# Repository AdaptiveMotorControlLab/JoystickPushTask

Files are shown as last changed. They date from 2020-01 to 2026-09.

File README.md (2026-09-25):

# Forelimb Object-Push Task

> ⚠️ **Work in progress.** This repository adapts the 2-axis joystick rig from
> [Mathis et al., 2017](https://doi.org/10.1016/j.neuron.2017.02.049) into a **1D forelimb object-push task**.
> The working rig VIs have been imported, and the rest-pad-to-reward success path is bench-tested.
> The push object is now a 3D-modeled joystick shaft with interchangeable tip-mounted handles
> (bar or rounded cube) meant to sit below the mouse.
> Animal-specific calibration, training presets and safety/edge-case validation remain in progress.

Forked and adapted from the original [JoystickControlSystem](https://github.com/AdaptiveMotorControlLab/JoystickControlSystem)
(Mathis lab). The original rig trained head-fixed mice to *pull* a 2-axis joystick against a lateral
magnetic perturbation. This fork keeps the same LabVIEW architecture and NI-DAQ backbone but reworks the
task into a goal-directed forward *push*.

## Task overview

Each trial:

```
forepaw on rest pad  →  trial starts  →  reach to object  →  push forward
  →  (optional axial resistance; hardware not yet active)  →  object held in target band
  →  auditory success cue  →  short delay  →  lick spout extends  →  water reward  →  spout retracts
```

Key differences from the original task:

- **1D push** instead of 2D pull — the task-relevant axis remains in the existing coordinate structure;
  the lateral axis is physically limited by the existing **1D-axis constrainer**.
- **Bounded target zone** — reward requires the object to *end and remain* within a target distance band (overshoot fails).
- **Rest-pad initiation** — a trial can only start when the object is home (spring-loaded) **and** the
  forepaw is on the rest pad, giving a clean pre-contact trial-start state.
- **Axial-resistance perturbation** (opposing the push) instead of a lateral kick. The mesoscope
  rig uses the original Mathis solenoid (McMaster `69905K25`). The training-rig copy is Ledex
  `195224-230`, received 02/09/26 but not yet installed. Its coil driver, Hydraulik-Kompetenz
  PVA 1.6 0–10 V, was ordered 25/09/26. `Dev1/ao0` / `MagnetPush_Dev1` is reserved for the command.
- **Delayed, retractable reward** with an immediate auditory success cue, separating push execution from
  licking/reward for cleaner neural alignment.
- **Planned session blocks** (via parameter files): Baseline → Random perturbation → Fixed perturbation → Washout.

## Current status

- Canonical VIs imported from the behavioural rig and pushed on 18 August 2026.
- Bench-validated path: object home + FSR paw gate → trial → success cue → adjustable delay → spout
  extension → water → consumption wait → spout retraction.
- The acquisition helper reads joystick X/Y, lick/frame signals and the new rest-pad channel.
- A fresh GitHub copy now opens and completes the full bench sequence on the rig PC using the
  compatible repository helper VIs.
- Safe startup now commands water/cue LOW, spout retract and magnet 0 V. One canonical Stop cleanly
  ends every parallel loop; idle, reward-delay and spout-extended Stop tests passed.
- `deliverWater_RIG1_cue.vi` provides manual day-1 habituation rewards: one Run gives a fixed
  50 ms auditory cue followed by the front-panel-selected water pulse, with no joystick requirement.
- Remaining validation includes repeated-cycle testing and explicit fail/timeout checks. LabVIEW's
  toolbar Abort remains emergency-only because it bypasses normal cleanup.
- STEP models exist for an 89 mm joystick shaft plus two tip-mounted handles: a 38 mm bar and a
  rounded cube with three offset holes. See [`mechanical/README.md`](mechanical/README.md).
- A printed joystick, handle and 1D-axis constrainer are already fitted on the rig. Further
  CAD prints wait until 21 September 2026. The rest-pad FSR was replaced on 8 September 2026,
  taped, and is working. Remaining build work includes spring return and a steel-ring target,
  installing the ordered PVA driver and force-calibrating the Ledex, mouse-specific calibration and training-stage
  controls/presets.

## Hardware

Existing rig hardware:

- NI-DAQ card, **PCIe-6321** (`Dev1` on the live rig)
- Joystick base/readout (Digi-Key 679-2501-ND)
- 3D-printed **1D-axis constrainer** ([STEP model](mechanical/3d-print/joystick-1d-axis-constrainer/README.md))
- 3D-modeled **joystick shaft** and interchangeable handles
  ([cube](mechanical/3d-print/joystick-handle-cube/README.md),
  [bar](mechanical/3d-print/joystick-handle-bar/README.md))

Mechanical adaptation in progress:

- One printed joystick, handle and 1D-axis constrainer are fitted for bench testing. Further
  CAD prints wait until 21 September 2026; compare the rounded cube's three offset holes when
  freezing the final mouse-relative reach and object weight.
- Add spring return to home and the steel-ring / washer target for the axial solenoid.

New components for the push task:

| Role | Component | DAQ channel |
| --- | --- | --- |
| Rest-pad paw sensor | Interlink **FSR 402** (solder tabs, 30-81794) + 10 kΩ divider | `Dev1/ai2` |
| Retractable lick spout | **Actuonix L12-30-50-12-I** linear actuator (0–5 V position mode, 12 V supply) | `Dev1/ao1` |
| Auditory success cue | **Adafruit 5 V active buzzer** (#1536) | `Dev1/port0/line1` |
| Axial resistance | Ledex **`195224-230`** (received 02/09/26; not installed). Driver ordered 25/09/26: Hydraulik-Kompetenz PVA 1.6 0–10 V | reserved `Dev1/ao0`  |
| Water valve | existing solenoid | `Dev1/port0/line0` |

> The validated live NI-MAX configuration, SCB-68A wiring and bench-test history are documented in
> [`RIG_INVENTORY.md`](RIG_INVENTORY.md).

> The PCIe-6321 has two AO channels. The working design reserves AO0 for axial resistance and uses
> AO1 for the lick-spout actuator; the auditory cue therefore uses a digital line.

## Software

The main VI is `Push Behaviour_MCHALABI.vi`. Its required local dependencies are
`avg joystick and frame trig lick3.vi`, `frame counter.vi` and `PushTask Globals.vi`.

The program retains the original occurrence-driven five-state architecture and trajectory logging while
adding the FSR gate, digital success cue, retractable-spout reward sequence and shared normal-stop
signal for all asynchronous loops. It requires LabVIEW and NI-DAQmx. Saved NI-MAX tasks are
machine-local and must be imported or configured on each rig. The validated task/channel map is
documented in [`RIG_INVENTORY.md`](RIG_INVENTORY.md), with the 20 August 2026 NI-DAQmx backup stored at
[`ni-max/JoystickPushTask_NIMAX_2026-08-20.nce`](ni-max/JoystickPushTask_NIMAX_2026-08-20.nce).

## Experimental settings file

The experimental parameters are loaded from a text file, one line per trial
(**27 tab-separated columns**). Columns 1–21 were mapped on 8 September 2026;
reward delay, cue duration and spout timing/voltages were added as columns
22–27 and runtime-tested on the rig on 9 September:
[`parameters/README.md`](parameters/README.md). Push = Y / `ai1`; lateral = X /
`ai0`. Column 19 is Case 0 `timeout`; column 20 is Case 3 `move time`.

Push training files (stages 2–8, including reward-delay ramping) live in
[`parameters/training/`](parameters/README.md). Habituation and perturbation
experiment blocks are not yet file-only stages.

The old front-panel controls remain temporarily as references/fallbacks, but
the live rig water loop now reads those six settings from each trial row. The
edited VI binary still needs transferring back from the rig PC into this
repository.

## Calibration

Water-valve pulse length was measured on the training rig on 8 September 2026.
Use **130 / 185 / 240 ms** for **4 / 6 / 8 µl**. The 200 ms bench default delivered
6.6 µl. Full table, fit and figures:
[`calibration/water-volume.md`](calibration/water-volume.md).

Joystick map (8 September 2026): **push = Y = `Dev1/ai1`** (white), **lateral = X =
`Dev1/ai0`** (red). Home is **2.50 V** / **2.525 V**. An eyeball 10 mm push was
2.50 → 2.20 V (~0.030 V/mm at this handle, vs the old demo 0.05 V/mm). See
[`calibration/joystick-volts-mm.md`](calibration/joystick-volts-mm.md).
Remeasure with a ruler before writing training files. Test all channels in
NI-MAX before running.

## Citation

Please cite the original work this task is built on:

- [Mathis et al., 2017](https://doi.org/10.1016/j.neuron.2017.02.049) — *Somatosensory Cortex Plays an
  Essential Role in Forelimb Motor Adaptation in Mice.*

We greatly thank Dr. Ed Soucy at the Harvard CBS Center for Neuroengineering for the original LabVIEW code
and expert advice throughout the development of this joystick system.

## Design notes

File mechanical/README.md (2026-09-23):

# Mechanical designs

CAD and fabrication files for the forelimb push-task rig: 3D-printed parts and
related build notes.

## Layout

| Folder | Use for |
| --- | --- |
| [3D-printed parts](3d-print/README.md) | 3D-printable meshes and project files (STL, 3MF, STEP, Fusion, etc.) |

Add new parts in a named subfolder (e.g. `3d-print/fsr-mount/`) so
revisions stay grouped. Prefer descriptive filenames with dimensions or revision when useful.

## Push object

CAD added 05 Sep 2026: an 89 mm joystick shaft plus two interchangeable tip-mounted handles.

- [Joystick shaft](3d-print/joystick/README.md)
- [Bar handle](3d-print/joystick-handle-bar/README.md) — 38 mm bar
- [Rounded-cube handle](3d-print/joystick-handle-cube/README.md) — current push-object candidate.
  Three holes set how close the front face sits to the mouse and rest pad, and they also shift
  weight relative to the joystick beneath the object.

The cube is meant to sit below the mouse in the natural forelimb workspace and present a
push-biased surface that discourages grasping like the original pull handles.

## 3D models

- [Joystick shaft](3d-print/joystick/README.md) — 89 mm STEP source and STL export
- [Joystick bar handle](3d-print/joystick-handle-bar/README.md) — 38 mm STEP source and STL export
- [Joystick rounded-cube handle](3d-print/joystick-handle-cube/README.md) — rounded-box STEP source and STL export
- [Joystick 1D-axis constrainer](3d-print/joystick-1d-axis-constrainer/README.md) — 38 × 38 × 41 mm STEP source and STL export
- [Ledex holder](3d-print/ledex-holder/README.md) — holder for the Ledex `195224-230`, 30 mm axis STEP source and STL export

One printed joystick, handle and 1D-axis constrainer are fitted for bench testing. Further
prints wait until 21 September 2026. Still to integrate: spring return to home, the
steel-ring / washer target, and final volts→mm calibration after the below-mouse geometry
is frozen.

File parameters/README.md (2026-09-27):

# Parameter files

Tab-separated doubles, **27 columns**, one line = one trial. Columns 1–21 were
mapped on the live VI on 8 September 2026. Columns 22–27 (reward delay, cue,
spout) are in the files as of 9 September 2026; the loader still has to grow
from 21 to 27 cases or those values are ignored.

## Column map (confirmed)

| Index | File column | Field | Notes |
| ---: | ---: | --- | --- |
| 0 | 1 | `home X1` | **ROI slot X — follows the white / push line** (09/09/26 hand test). Pair with col 3. Loader name “X” is not NI-MAX `ai0`. |
| 1 | 2 | `home Y1` | **ROI slot Y — follows the red / lateral line.** Pair with col 4. |
| 2 | 3 | `home X2` | No ×2 on the live loader (checked 09/09/26). |
| 3 | 4 | `home Y2` | |
| 4 | 5 | `home TO` | ms. Object-in-home **and** FSR paw. |
| 5 | 6 | `start X1` | Unused while `start TO` = 0. |
| 6 | 7 | `start Y1` | |
| 7 | 8 | `start X2` | |
| 8 | 9 | `start Y2` | |
| 9 | 10 | `start TO` | Keep **0**. |
| 10 | 11 | `end X1` | **Push target** (white / `ai1`). Lower V = farther forward. |
| 11 | 12 | `end Y1` | **Lateral** (red / `ai0`). Keep wide around 2.525 V. |
| 12 | 13 | `end X2` | |
| 13 | 14 | `end Y2` | |
| 14 | 15 | `end TO` | ms dwell inside the end box. |
| 15 | 16 | `mag` | Keep **0** until resistance. |
| 16 | 17 | `magtime` | Dummy 25 on zero-force rows. |
| 17 | 18 | `watertime` | ms. 130 / 185 / 240 → 4 / 6 / 8 µl. |
| 18 | 19 | `timeout` | Case 0 inter-trial wait (ms). |
| 19 | 20 | `move time` | Case 3 movement window (ms). **400 is short.** |
| 20 | 21 | `light` | Keep **0**. |
| 21 | 22 | `reward delay` | ms after cue, before spout extend. Stage 6. |
| 22 | 23 | `cue duration` | ms. Bench 50. |
| 23 | 24 | `spout extend` | V. Bench **3.0**. |
| 24 | 25 | `spout settle` | ms. Bench **2000**. |
| 25 | 26 | `consumption` | ms. Bench **2000**. |
| 26 | 27 | `spout retract` | V. Bench **0**. |

Boxes are two corners `(X1, Y1, X2, Y2)`. Write the smaller voltage first in
each pair. **Do not trust the words X and Y.** 09/09/26: a file with the
forward band in the Y slots paid out only when **red** moved. The forward
band now goes in the **X** slots so a white-line push is the target. Likely
cause: after `joysticklickframe_push` was reordered to `[Y, X, FSR]`, Case 3
still compares index 0 to the X box and index 1 to the Y box.

## Shared settings (all written files)

Scale is the 08/09/26 eyeball **0.030 V/mm**, push rest **2.50 V** (lower V =
forward). Remeasure with a ruler before treating millimetres as final.

| Field | Value | Why |
| --- | --- | --- |
| Home X (push) | 2.46–2.54 | Rest 2.50 ± 0.035 |
| Home / end Y (lateral) | 2.40–2.65 | Wide so red noise does not fail the trial |
| `home TO` | 250 ms | User 09/09/26 |
| `start TO` | 0 | Rest pad + home replace the start-box wait |
| `watertime` | 185 ms | ~6 µl |
| `timeout` (ITI) | 1000 ms | |
| `move time` | 30000 ms | Clock still starts at Case 2, not paw lift |
| `mag` / `magtime` / `light` | 0 / 25 / 0 | No resistance yet |
| `reward delay` | 0 ms stages 2–5; stage 6 ramps 0/250/500/1000; 500 ms expert/shadow | Final default can move to 1000 ms after validation |
| `cue duration` | 50 ms | |
| `spout extend` / `retract` | 3.0 V / 0 V | |
| `spout settle` / `consumption` | 2000 / 2000 ms | |

Advance a stage after the criterion on **two consecutive days**. Change only
one important thing at a time.

## Files that exist

| File | Stage | Push end box (X) | ~mm from rest | `end TO` | Rows | Extra |
| --- | --- | --- | --- | --- | --- | --- |
| [push_bench_wide-zone.txt](push_bench_wide-zone.txt) | Hand test | 2.20–2.35 | 5–10 mm, wide | 50 | 80 | delay 0 |
| [training/02_micro_push.txt](training/02_micro_push.txt) | 2 Discovery | 2.15–2.45 | past ~1.7 mm, no far wall | **0** | 200 | delay 0 |
| [training/02_micro_push_day1_5s_8ul.txt](training/02_micro_push_day1_5s_8ul.txt) | 2 Day-1 pilot | 0.00–2.27 | permissive threshold from recalibrated 2.275–2.425 home | **0** | 250 | 100 ms home hold; 5 s move; 8 µl; fixed 3 V spout |
| [training/03_proximal_zone.txt](training/03_proximal_zone.txt) | 3 Proximal | 2.35–2.45 | 1.7–5.0 mm | 50 | 400 | delay 0 |
| [training/04_zone_translate_1.txt](training/04_zone_translate_1.txt) | 4 Shift 1 | 2.31–2.41 | 3.0–6.3 mm | 50 | 400 | delay 0 |
| [training/04_zone_translate_2.txt](training/04_zone_translate_2.txt) | 4 Shift 2 | 2.26–2.36 | 4.7–8.0 mm | 50 | 400 | delay 0 |
| [training/04_zone_translate_3.txt](training/04_zone_translate_3.txt) | 4 Final broad | 2.24–2.35 | 5.0–8.7 mm | 50 | 400 | delay 0 |
| [training/05_zone_refine.txt](training/05_zone_refine.txt) | 5 Refine | 2.27–2.34 | 5.3–7.7 mm, ~2.3 mm wide | 50 | 400 | delay 0 |
| [training/06_delay_0.txt](training/06_delay_0.txt) | 6 Delay 0 | same as expert | same | 50 | 400 | reward delay **0** |
| [training/06_delay_250.txt](training/06_delay_250.txt) | 6 Delay 250 | same | same | 50 | 400 | delay **250** |
| [training/06_delay_500.txt](training/06_delay_500.txt) | 6 Delay 500 | same | same | 50 | 400 | delay **500** |
| [training/06_delay_1000.txt](training/06_delay_1000.txt) | 6 Delay 1000 | same | same | 50 | 400 | delay **1000** |
| [training/07_expert.txt](training/07_expert.txt) | 7 Expert | same as refine | same | 50 | 500 | delay **500** |
| [training/08_shadow.txt](training/08_shadow.txt) | 8 Shadow | same as expert | same | 50 | 300 | delay **500** |

`08_shadow` is geometrically identical to expert (`mag = 0`). The 50 / 75 / 100 / 75
block labels are not in the file; they are session notes until the magnet exists.

Do not load `Full_shoterPull_Training_Task_RIG1` for the push task.

## Stages that are **not** a parameter file

| Stage | Why | What to do instead |
| --- | --- | --- |
| 1 Habituation (cue → water, no push) | Water loop only wakes on Case 4 | Run `deliverWater_RIG1_cue.vi` once per manual reward. It gives a fixed 50 ms cue, then water for the front-panel `Water on time (ms)` value. |
| Rest only (fallback) | Would reward pad contact without a push | LabVIEW if a mouse never touches the pad. Not a default. |
| 6 Delay / retractable spout | Files exist (`06_delay_*`) | Load 0 → 250 → 500; use 1000 only if desired and tolerated. Do not change the zone in those sessions. |
| 8 Shadow block labels | No column for block ID; magnet still absent | Run `08_shadow` as one 300-trial zero-force session. Split 50/75/100/75 later if needed. |
| 9 Experiment (Baseline / Random / Fixed / Washout) | Random/Fixed need a force-calibrated magnet | Baseline ≈ `07_expert`. Do not write `mag ≠ 0` files yet. |

## Front panel during these files

The live rig loader and water loop were extended and runtime-tested on
09/09/26. The six values now come from the file. Keep the old FP controls
temporarily as visible references/fallbacks until the edited VI is transferred
back to this repository and re-tested from a clean copy. Log the selected
filename with the session.

For `02_micro_push_day1_5s_8ul.txt`, set the front-panel
`Session start spout (V)` control to **3.0 V** before Run. The file also writes
3.0 V for both extend and retract, so the spout remains extended throughout
the session; normal Stop still retracts it. Bench testing on 27/09/26 corrected
the loader/water-loop cluster-order mismatch for `reward delay` and
`spout retract`. The front-panel captions were corrected separately without
changing the working underlying labels.

## LabVIEW: loader extension completed on rig 09/09/26

The following implementation was completed and reported working on the rig PC.
The repository `.vi` binary still needs to be replaced with that tested copy.

1. Stop the VI. Save a backup.
2. On the front panel, expand the cluster inside **`exp para array`** from
   21 to 27 numeric fields. Copy six existing DBL fields inside the cluster
   and rename their labels exactly: `reward delay`, `cue duration`,
   `spout extend`, `spout settle`, `consumption`, `spout retract`. If the
   cluster is a typedef, open and edit the typedef instead. The loader cases
   cannot Bundle By Name into fields that do not exist in this cluster.
3. Parameter-loader For Loop: change the **21** to **27** (loop count and any
   “init array of 21 zeros”).
4. Add cases **21–26** on that Case Structure (`i`), same pattern as `home X1`:
   Scan From String `%f` → bundle into a new named field.
   - 21 `reward delay`
   - 22 `cue duration`
   - 23 `spout extend`
   - 24 `spout settle`
   - 25 `consumption`
   - 26 `spout retract`
5. Water loop (the Flat Sequence that already uses `watertime`):
   - Wait after cue LOW → **`reward delay`** from this trial (not the FP)
   - Cue wait → **`cue duration`**
   - Extend write → **`spout extend`**
   - Settle wait → **`spout settle`**
   - After water LOW → **`consumption`**
   - Retract write → **`spout retract`**
   Copy how `watertime` is already unbundled for the current trial.
6. Save. Load `06_delay_250.txt`. Success should wait **250 ms** after the cue
   before the spout moves. Then try `06_delay_0.txt` — spout should move
   immediately after the cue.

Habituation (cue→water with no push) is still a separate LabVIEW mode. These
columns do not create that.

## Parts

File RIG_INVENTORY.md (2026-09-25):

# Live Rig Inventory

> Work in progress. Recorded from NI Measurement & Automation Explorer (NI-MAX) on the animal-facility rig PC.

## DAQ hardware

- Device name: `Dev1`
- Model: **National Instruments PCIe-6321**
- Serial number: `01C8BE45`
- NI-MAX status during inventory: Present
- Device temperature during inventory: approximately 32.8 °C
- Earlier project notes incorrectly assumed PCIe-6251; use the live PCIe-6321 configuration as authoritative.
- `SimDev1` is an NI simulated DAQ device, not the physical rig card; do not assign live tasks to it.

Calibration information shown by NI-MAX:

- External calibration: 13 September 2017
- Recommended next external calibration: 13 September 2019 (overdue)
- Last self-calibration: 13 August 2022

Do not initiate calibration during wiring/inventory. Flag the overdue external calibration to the lab
and decide separately whether traceable analog accuracy is required before experiments.

NI-MAX device configuration:

- Connector 0 accessory setting: None
- `port0` power-up state: all eight lines tristated (high-impedance)

Configuration backup:

- Full NI-DAQmx 17.0 configuration exported from `My System` on 20/08/26 after the X/Y-order fix
  and successful GitHub-copy bench test.
- Repository file:
  [`ni-max/JoystickPushTask_NIMAX_2026-08-20.nce`](ni-max/JoystickPushTask_NIMAX_2026-08-20.nce)
- This is a disaster-recovery snapshot, not a substitute for reviewing physical channels before
  import. Inline DAQmx channels created directly by LabVIEW may not appear as saved tasks.

Official PCIe-6321 capacity:

- 16 single-ended or 8 differential analog inputs
- 2 analog outputs
- 24 bidirectional digital I/O lines
- 4 general-purpose counters (`ctr0`–`ctr3`)

Other devices visible in NI-MAX:

- PS3Eye Camera → `cam2`
- DMK 37BUX287 camera → `cam3`
- Serial port → `COM1`
- USB3 Vision Device (unused) → `USB-0`

## Existing NI-DAQmx tasks

- `joysticklickframe`
- `joysticklickframe_push`
- `Magnets_Dev1`
- `MagnetPush_Dev1`
- `Water_Dev1`
- `SuccessCue_Dev1`
- `LickSpout_Dev1`
- `rest_pad_test_Dev1`
- `success_cue_test_Dev1`
- `lick_spout_motor_test_Dev1`
- `frame counter_Dev1`
- `MyPulseOutputTask`
- `testing1blox_2labviews`

## Live LabVIEW program audit — 12/08/26

- The edited behavioural-rig hierarchy was imported into the repository as
  `Push Behaviour_MCHALABI.vi`; untouched `Pull_Behaviour_march2020` remains the fallback.
- Screenshots confirm the expected parameter loader, five-case trial state machine, occurrence-driven
water loop, and lower occurrence-driven perturbation/laser loop.
- The working push VI now performs:
  `cue HIGH → cue wait → cue LOW → reward delay → spout extend → settle → water HIGH →
  explicit watertime wait → water LOW → consumption wait → spout retract`.
- The lower occurrence loop contains both `Magnets_Dev1` analog writes and `Dev1/ctr1` laser-pulse
generation. Magnet support was preserved but converted to `MagnetPush_Dev1` on AO0 only; the laser
branch was not removed.
- `avg joystick and frame trig lick3.vi` uses `joysticklickframe` with DAQmx Analog 2D
`NChan NSamp`, averages indexed channels 0–3, builds a four-value array, and enqueues it as
`joystick pos`. This 12/08 audit led to the installed `joysticklickframe_push` task, which adds
`Dev1/ai2` as queue element index 2 while keeping the original global task unchanged.
- The attempted LabVIEW **Duplicate hierarchy to new location** copy was deleted because the expected
VI was not present in the selected folder. The entire containing folder was then copied manually
and marked with the suffix `- PushVersion - working`. This is the push-task working hierarchy; the
original `LabView files` folder remains the untouched operational baseline.
- Git cannot automatically merge independently changed `.vi` binaries.
- Core working-VI bench validation passed 18/08/26: first-trial rest-pad gating, cue, spout
extension, primed water delivery, consumption wait and retraction all worked across three spaced
successful trials. Fail/timeout behavior was reported working but still needs an explicit,
documented re-test. Abort-path output cleanup has not been specifically validated.
- Fresh GitHub-copy validation passed on the rig PC 20/08/26 after correcting the NI-MAX X/Y channel
  order and replacing the repository's unusable `frame counter.vi` with the compatible copy from the
  working hierarchy. The main VI opened with a healthy Run arrow and completed the full bench sequence.
- Manual day-1 habituation VI `deliverWater_RIG1_cue.vi` was built and bench-tested on 23/09/26.
  Each Run performs `Dev1/port0/line1 HIGH → 50 ms → LOW`, then the original
  `Dev1/port0/line0 HIGH → Water on time (ms) → LOW` sequence. The cue task is cleared before the
  water task is created, enforcing cue-before-water order. This VI has no joystick requirement and
  does not move the lick spout. Do not run the push VI, `SuccessCue_Dev1`, or
  `success_cue_test_Dev1` concurrently because they share the buzzer line.
- Safe startup/normal shutdown validated 20/08/26:
  - one-shot startup sequence commands `Water_Dev1=False`, `SuccessCue_Dev1=False`,
    `LickSpoutMotor_Dev1=0 V` and `MagnetPush_Dev1=0 V`;
  - stale runtime task references `Magnets` and `frame counter` were corrected to
    `MagnetPush_Dev1` and `frame counter_Dev1`;
  - invalid UI-control references could not stop the asynchronous acquisition/frame-counter VIs, so
    required helper `PushTask Globals.vi` now distributes one Boolean `stop all` signal;
  - the canonical main Stop now ends all parallel loops and returns the Run arrow to idle without DAQ
    errors. Idle, reward-delay and spout-extended Stop tests passed with water/cue OFF and final spout
    retraction.
- Toolbar **Abort Execution** remains emergency-only: it bypasses remaining LabVIEW sequence frames.
  If used after a hang, first make outputs safe when possible and rerun the initializer afterward.

## Confirmed task configuration

### `joysticklickframe`

- Purpose: reads the existing joystick position.
- `X_POS` → `Dev1/ai0`
- `Y_POS` → `Dev1/ai1`
- Input range: −10 V to +10 V
- Terminal configuration: Differential
- Acquisition: Continuous Samples
- Sample rate: 10 kHz

Do not assign `ai0` or `ai1` to the new FSR rest-pad sensor.

### `joysticklickframe_push` — created 12/08/26

- New independent AI task created for the working push-task hierarchy; original
`joysticklickframe` remains unchanged.
- Corrected channel order confirmed 20/08/26 as `Dev1/ai1`, `Dev1/ai0`, `Dev1/ai2`
  (`Y_POS`, `X_POS`, FSR). The first push-task configuration used `ai0`, `ai1`, `ai2`, which
  swapped X/Y relative to the unchanged LabVIEW array-index convention inherited from the old task.
- Final channel configuration: `ai0` and `ai1` differential ±10 V; `ai2` RSE, 0–5 V.
- Final timing: Continuous Samples, 10 samples/read, 10 kHz.
- Saved NI-MAX test passed 12/08/26: joystick X, joystick Y, and FSR signals were all visible
simultaneously; FSR responded as expected.
- Working-copy `avg joystick and frame trig lick3.vi` was updated and saved to select
`joysticklickframe_push`; original hierarchy remains pointed at `joysticklickframe`.
- Working-copy main VI Case 0 now reads queue element index 2 into a `rest pad voltage` indicator;
`rest pad voltage > rest pad threshold (V)` now drives a `paw on rest pad` Boolean indicator.
Starting threshold is 0.10 V pending animal-mounted calibration.
- A new AND combines the original X/Y home-ROI result with `paw on rest pad` before the existing
`home TO` hold logic. The separate inter-trial timeout gate is unchanged.
- Runtime test passed: index-2 FSR voltage and `paw on rest pad` changed correctly when Case 0 became
active after a completed/rewarded trial. The apparent initial failure was expected Case Structure
behavior—the indicator does not update while another case executes.
- Working-VI state shift-register initializer changed from 1 to 0 so sessions start in Case 0.
Fresh-run validation passed 12/08/26: the first trial remained gated until paw contact.

### `Magnets_Dev1`

- Purpose: controls the existing two-axis magnetic perturbation hardware.
- `VoltageOut` → `Dev1/ao0`
- `VoltageOut_0` → `Dev1/ao1`
- Output range: −10 V to +10 V
- Generation mode: 1 Sample (On Demand)
- Both available PCIe-6321 analog outputs are currently included in this task.
- The NI-MAX screen showed 1.1 V as the configured test value for both channels; the task was not run.

`Magnets_Dev1` is retained only as an original/legacy task. The working push VI no longer references
it. Its replacement is `MagnetPush_Dev1` on AO0 only, leaving AO1 exclusively available to
`LickSpout_Dev1`.

### `Water_Dev1`

- Purpose: controls the existing water-solenoid output.
- `DigitalOut` → `Dev1/port0/line0`
- Output type: Digital Line Output
- Generation mode: 1 Sample (On Demand)
- `Invert Line`: unchecked

Physical active-high behavior is verified: NI-MAX False→True→False and the LabVIEW sequence both
produce valve clicks and water. The line must be primed and bubble-free before short pulses are
reliable. Delivered volume was measured gravimetrically on 8 September 2026
(50 pulses per width; empty cup 2.94 ± 0.02 g):

`µl / pulse = 0.0350 × t(ms) − 0.48` (R² = 0.998).

Use **130 ms ≈ 4 µl**, **185 ms ≈ 6 µl**, **240 ms ≈ 8 µl**. The previous 200 ms
bench pulse was 6.6 µl. Full table and figures:
[`calibration/water-volume.md`](calibration/water-volume.md).

### `frame counter_Dev1`

- Purpose: counts incoming frame/synchronization pulses.
- Counter resource: `Dev1/ctr0`
- Input terminal: `PFI8`
- Active edge: Rising
- Initial count: 0
- Direction: Count Up
- Acquisition: 1 Sample (On Demand)

Each LOW→HIGH transition arriving on `PFI8` increments counter 0. Keep both `ctr0` and `PFI8`
reserved for the existing frame synchronization.

### `MyPulseOutputTask`

- Purpose: not yet traced physically; likely an existing synchronization/trigger pulse output.
- Counter resource: `Dev1/ctr1`
- Output terminal: `PFI13`
- Generation: Continuous Pulses
- Idle state: Low
- Initial delay: 0 s
- HIGH time: 10 ms
- LOW time: 10 ms
- Resulting pulse frequency: 50 Hz

Keep both `ctr1` and `PFI13` reserved until the task's physical destination and LabVIEW use are
identified. The PCIe-6321 has four counters: saved tasks account for `ctr0` and `ctr1`; `ctr2` and
`ctr3` are not represented in the saved-task list. The active success buzzer still only needs a
spare ordinary digital-output line.

### `testing1blox_2labviews`

- Likely purpose: legacy/diagnostic analog-input test; confirm before deleting or ignoring.
- `Voltage_0` → `Dev1/ai0`
- `Voltage_1` → `Dev1/ai1`
- Input range: −10 V to +10 V
- Terminal configuration: Differential
- Acquisition: N Samples
- Samples to read: 100
- Sample rate: 1 kHz

This task duplicates the same physical AI channels used by `joysticklickframe`. Saved tasks may
overlap resources; they conflict only if software attempts to reserve/run them simultaneously.
Its finite 100-sample configuration and name suggest a test task, but check LabVIEW references
before removing it.

## Breakout box

- Model: **NI SCB-68A** shielded connector block, 68 screw terminals
- Box label: `rig1`
- Connects to `Dev1` via the 68-pin cable; NI-MAX itself still lists the accessory as "None"
- Contains a custom breadboard/component area already populated with user-added circuitry
- The lid label shows S1/S2 switch diagrams for the onboard temperature sensor. Because the joystick
uses AI0/AI8 in differential mode, the temp sensor must be in the disabled (factory default)
position; confirm the physical switches before touching AI0.

### Red regulator module (joystick power supply)

Traced 04/08/26. This is an adjustable DC-DC converter mounted in the breadboard area:

- `IN+` ← red wire from **terminal 14 (+5 V)**
- `IN−` ← black wire from **terminal 50 (D GND)**
- `OUT+` → yellow wire into the rig enclosure, entering the joystick base
- `OUT−` → grey wire into the rig enclosure, entering the joystick base

This supplies the joystick's excitation voltage, and its trim pot is almost certainly what sets the
documented ~2.55 V resting output. **Do not remove, repower or re-trim this module** — doing so would
silently recalibrate every position reading. Note that this consumes **terminal 14**, so the second
+5 V terminal (**8**) must be used for the FSR excitation.

### Laser interlock — SAFETY CRITICAL

**Terminal 42 (PFI 3 / P1.3)**, with **terminal 7 (D GND)** as its return, is wired to a unit labelled
`MDL-III-635L-200mW` (`DC30041`). That is a **200 mW, 635 nm laser — Class 3B**, driven from the
black key-switched supply beside the breakout box.

- No saved NI-MAX task references PFI 3, so this line is commanded directly from LabVIEW code.
- Never toggle PFI 3 / P1.3, and never run an unknown digital task, while the laser key is enabled.
- Keep the laser supply keyed off during all bench testing of the new hardware.

### Saved NI-MAX tasks are not the full picture

PFI 3 is physically wired to the laser but appears in **no** saved NI-MAX task. LabVIEW therefore
creates at least some DAQmx channels inline. Treat the saved-task list as incomplete and confirm
channel usage against the VI before claiming any line is free.

### SCB-68A terminal map (X Series / 63xx label, verified against NI documentation)

Analog input (differential pairs `AI x+` with `AI x+8`):

| Signal | Terminal | Signal | Terminal |
| --- | --- | --- | --- |
| AI 0 (AI 0+) | 68 | AI 8 (AI 0−)  | 34 |
| AI 1 (AI 1+) | 33 | AI 9 (AI 1−)  | 66 |
| AI 2 (AI 2+) | 65 | AI 10 (AI 2−) | 31 |
| AI 3 (AI 3+) | 30 | AI 11 (AI 3−) | 63 |
| AI 4 (AI 4+) | 28 | AI 12 (AI 4−) | 61 |
| AI 5 (AI 5+) | 60 | AI 13 (AI 5−) | 26 |
| AI 6 (AI 6+) | 25 | AI 14 (AI 6−) | 58 |
| AI 7 (AI 7+) | 57 | AI 15 (AI 7−) | 23 |

- AI GND: 67, 32, 64, 29, 27, 24, 56, 59
- AI SENSE: 62

Analog output:

- AO 0 → 22, AO GND → 55
- AO 1 → 21, AO GND → 54

Digital port 0:

| Line | Terminal | Line | Terminal |
| ---- | --- | ---- | --- |
| P0.0 | 52 | P0.4 | 19 |
| P0.1 | 17 | P0.5 | 51 |
| P0.2 | 49 | P0.6 | 16 |
| P0.3 | 47 | P0.7 | 48 |

- +5 V: 14 and 8
- D GND: 53, 18, 50, 15, 13, 12, 44, 9, 7, 4, 36, 35
- PFI 8 / P2.0 → 37 (frame counter input); PFI 13 / P2.5 → 40 (pulse output)

### Physically occupied terminals (surveyed 04/08/26)

| Terminal | Signal | Connected to |
| --- | --- | --- |
| 68 | AI 0 (AI 0+) | joystick X position |
| 34 | AI 8 (AI 0−) | joystick X position, differential return |
| 33 | AI 1 (AI 1+) | joystick Y position |
| 66 | AI 9 (AI 1−) | joystick Y position, differential return |
| 67 | AI GND | analog ground |
| 27 | AI GND | analog ground |
| 8 | +5 V | FSR divider excitation |
| 65 | AI 2 | FSR rest-pad signal |
| 64 | AI GND | FSR divider return |
| 21 | AO 1 | Actuonix 0–5 V position command |
| 54 | AO GND | Actuonix command/external-PSU common |
| 52 | P0.0 | water solenoid |
| 18 | D GND | water solenoid return |
| 17 | P0.1 | Adafruit success buzzer positive |
| 15 | D GND | Adafruit success buzzer return |
| 14 | +5 V | red regulator module `IN+` |
| 50 | D GND | red regulator module `IN−` |
| 42 | PFI 3 / P1.3 | 635 nm 200 mW laser control |
| 7 | D GND | laser return |

### Terminals confirmed physically empty

- **22 (AO 0)** — reserved for the axial-resistance magnet (EU/CH Ledex equivalent); currently no wire landed
- 37 (PFI 8) and 40 (PFI 13) — not in the occupied list
- AI10 terminal 31 remains unused because FSR AI2 uses RSE, not differential
- Remaining unused P0 lines: P0.2–P0.7

### Analog-output split and current physical state

AO1 terminal 21 is now physically wired to the Actuonix command input. AO0 terminal 22 remains
physically empty until the received training-rig magnet is installed. The old `Magnets_Dev1` task still
contains both channels but is not used by the working push VI; `MagnetPush_Dev1` owns AO0 and
`LickSpout_Dev1` owns AO1.

Consequences:

- An AO channel **is** available for the Actuonix, so the lick spout is no longer blocked.
- Confirmed 12/08/26: this behavioural training rig had **no perturbation magnet hardware**.
- Perturbation magnet hardware already exists on the mesoscope rig (original Mathis tubular solenoid).
- Ordered 27/08/26 from Contact Evolution SA, Payerne and received 02/09/26:
  **Ledex / Johnson Electric `195224-230`** (tubular STA 75L pull, 12 VDC, 7 W)
  (https://shop.contact-evolution.ch/en/home/26325-195224-230.html).
  The Ledex is the Swiss/EU equivalent of the original McMaster `69905K25`. The Ledex is not yet mounted or wired.
  Install **axially** (opposing the push), not laterally.
  Coil driver ordered 25/09/26: Hydraulik-Kompetenz **PVA 1.6 0–10 V**
  (CHF 260; not the 4–20 mA SKU). It is a current-regulated PWM amplifier. AO0 is the
  0–10 V command, and coil power comes from the reserved 12 V supply, not the DAQ pin.
  The Bürkert Type 8605 (`316532`) ordered earlier remains the ~2 December spare unless
  that order is cancelled. Mesoscope-rig drive copying is not the plan.
  Include a steel ring / ferromagnetic target on the push object (Mathis 2017).
  Force-calibrate on the bench; do not assume the paper 2.2 V / 100 ms pulse transfers.
  Keep `mag = 0` until the unperturbed task is stable.
- `Magnets_Dev1` must no longer reserve AO1. Target split: one-channel on-demand magnet task on AO0
  and one-channel on-demand Actuonix task on AO1.
- NI documentation permits one software-timed/on-demand AO task per physical AO channel. Both current
  outputs use on-demand writes, so magnet AO0 and spout AO1 can coexist; hardware-timed AO would
  require a combined task because the PCIe-6321 has one AO timing engine.
- Live LabVIEW magnet-loop audit 18/08/26 shows two `Analog 1D DBL NChan 1Samp` writes using
  `Magnets_Dev1`: one command write and one later reset write. Both can be converted to a new
  one-channel AO0 task without altering the separate counter/laser logic.
- `MagnetPush_Dev1` created 18/08/26: `Dev1/ao0` only, ±10 V, 1 Sample (On Demand). Saved but not
  physically exercised because no magnet was connected on this rig at that time.
- Working-copy LabVIEW magnet task constant changed to `MagnetPush_Dev1`; its two DAQmx Write nodes
  were converted to `Analog DBL 1Chan 1Samp`. Activation writes scalar `mag`; reset writes scalar
  zero; both retain auto-start=True. Magnet code now addresses AO0 only and cannot command AO1.
  Working VI retained a solid Run arrow after the refactor.
- Live water-loop audit 18/08/26 confirms its existing Flat Sequence performs
  `Water_Dev1 HIGH → wait watertime → Water_Dev1 LOW`; new cue/spout frames should wrap these without
  replacing them.
- Final output tasks created 18/08/26:
  - `SuccessCue_Dev1` → `Dev1/port0/line1`, digital one-sample/on-demand
  - `LickSpout_Dev1` → `Dev1/ao1`, 0–5 V, one-sample/on-demand
  Existing test tasks remain saved but must not run concurrently on the same lines.
- Working water loop now begins with `SuccessCue_Dev1 HIGH → 50 ms wait → SuccessCue_Dev1 LOW`
  before the preserved water sequence. Runtime test passed 18/08/26: one brief cue occurred per
  successful trial and stopped cleanly.
- Spout/reward frames added with initial bench defaults: reward delay 0 ms; extend command 1.0 V;
  settle 3000 ms; consumption 2000 ms; retract command 0 V. Both `LickSpout_Dev1` analog writes use
  scalar `Analog DBL 1Chan 1Samp` with auto-start=True.
- First LabVIEW sequence test 18/08/26: actuator made the expected coarse 1.0 V extension, followed
  by slight continued fine extension coincident with its familiar audible settling sound. The
  L12-I requires a continuously held setpoint and uses a fixed internal digital position controller;
  time repeated trials to confirm all fine motion/noise stops within the 3000 ms settle window.
- Bench controls later set to extend=3.0 V, settle=2000 ms, consumption=2000 ms, retract=0 V,
  reward delay=0 ms and cue=50 ms; settling sound/fine movement accepted provisionally.
- Resolved water-delivery diagnostic (18/08/26): an initially dry 200 ms automated pulse failed
  because the tubing contained air. A diagnostic 1000 ms pulse primed the line; the immediately
  repeated 200 ms pulse then worked. The 1000 ms value was diagnostic only and must not be used for animals.
- Immediate post-prime retest at 200 ms worked. Multiple air bubbles were observed in the tubing;
failed short-pulse delivery was therefore caused by an unprimed/air-filled water path, not DAQ or
LabVIEW. Inspect and prime until bubble-free before each session. Volume vs pulse
length was measured 08/09/26; see
[`calibration/water-volume.md`](calibration/water-volume.md).
- Three spaced complete trials then passed with cue, extension, water and retraction on every trial.
  The explicit 200 ms Wait is nominally the same intended duration as original `watertime=200`, but
  exact pulse equivalence has not been electrically measured; functional calibration should use
  delivered water mass/volume.
- Random/Fixed perturbation blocks have not yet been physically bench-tested on this training rig;
  install the ordered PVA 1.6 driver and validate its hardware mapping, force and sign before enabling them.

### Channel availability implications

- The joystick task runs in **differential** mode, so it physically consumes AI 0, AI 8, AI 1 and
AI 9 (terminals 68, 34, 33, 66). `ai2` and above are the genuinely free analog inputs.
- `P0.0` (terminal 52) is the water valve. `P0.1`–`P0.7` are candidate buzzer lines.
- Port 0 lines can source up to 24 mA; PFI lines only 16 mA. The Adafruit #1536 buzzer draws roughly
24 mA at 5 V, so it must use a **port 0** line, and even then it sits at the specification limit —
add a small transistor/MOSFET driver if the tone is weak or the line is loaded.
- Terminal 14 (+5 V) is taken by the regulator module; use **terminal 8** for FSR excitation.

## Still to inspect

- [x] `Magnets_Dev1`: `Dev1/ao0` + `Dev1/ao1`, −10 V to +10 V, on-demand
- [x] AO1 terminal 21 is occupied by the Actuonix command; AO0 terminal 22 remains empty for the magnet
- [x] Confirmed 12/08/26: no perturbation magnet then on training rig; magnet existed on mesoscope rig only
- [x] Ordered 27/08/26: Ledex `195224-230` from Contact Evolution SA (Payerne), the Swiss/EU equivalent of McMaster `69905K25`
- [x] Ledex `195224-230` received 02/09/26; holder STEP model added 03/09/26
- [x] Ordered 25/09/26: Hydraulik-Kompetenz PVA 1.6 0–10 V (CHF 260) as the Ledex coil driver. Not the 4–20 mA SKU. Bürkert Type 8605 / `316532` stays the ~2 December spare unless cancelled
- [ ] Print/fit holder, install the PVA driver, wire AO0 terminal 22 and force-calibrate the Ledex
- [x] `Water_Dev1`: `Dev1/port0/line0`, digital line output, on-demand, not inverted in NI-MAX
- [x] `frame counter_Dev1`: `Dev1/ctr0`, rising edges from `PFI8`
- [x] `MyPulseOutputTask`: `Dev1/ctr1` output on `PFI13`, continuous 50 Hz pulse train
- [ ] Confirm whether PFI 8 / PFI 13 are only connected when the imaging system is attached
- [x] `testing1blox_2labviews`: duplicate AI test on `Dev1/ai0` + `Dev1/ai1`, 100 samples at 1 kHz
- [ ] Search LabVIEW/project references before classifying `testing1blox_2labviews` as unused
- [x] Device capacity checked against PCIe-6321 specification: 16 SE/8 differential AI, 2 AO, 24 DIO, 4 counters
- [x] Physical connector/breakout-box model: NI SCB-68A, labelled `rig1`
- [x] Recorded which SCB-68A screw terminals physically have wires landed in them
- [x] Red breadboard module identified as the joystick supply regulator
- [x] PFI 3 traced to a Class 3B 635 nm laser
- [ ] Audit the VI for inline DAQmx channels not represented in saved NI-MAX tasks
- [ ] Confirm S1/S2 temperature-sensor switch positions

## New channels and planned magnet installation

| Component | Channel | SCB-68A terminals | Status |
| --- | --- | --- | --- |
| FSR 402 rest pad | `Dev1/ai2` | signal → 65, ground → AI GND (64), excitation → +5 V (**8**, not 14) | replaced 08/09/26 after 04/09 tail rip; fixed on rail with protective tape; working. Threshold/hysteresis still to calibrate |
| Adafruit #1536 buzzer | `Dev1/port0/line1` | `+` → 17 (P0.1), `−` → 15 (D GND) | installed; NI-MAX and 50 ms LabVIEW success-cue tests passed |
| Actuonix lick spout | `Dev1/ao1` | signal → 21, reference → AO GND (54), motor power from separate 12 V PSU with shared ground | installed; `LickSpout_Dev1` and full extend/water/retract sequence passed across three spaced trials |
| Axial magnet Ledex `195224-230` | `Dev1/ao0` | command → 22, AO GND shared with drive electronics; coil power **not** from the DAQ pin | coil received 02/09/26; driver ordered 25/09/26 (Hydraulik-Kompetenz PVA 1.6 0–10 V). Not mounted or wired. Mount axially; steel-ring target on push object |

Leave `ao0` (terminal 22) reserved for the Ledex until its drive is installed.

### Buzzer installation — 06/08/26

- Adafruit #1536 manufacturing wash seal removed; buzzer was not washed.
- Positive/long lead wired to terminal 17 (`P0.1`).
- Negative/short lead wired to terminal 15 (`D GND`).
- Direct-drive test chosen for initial prototype. Official nominal current is 15 mA, but independent
measurements report up to approximately 24 mA at 5 V, equal to the PCIe-6321 P0 per-line limit.
Treat direct drive as provisional; stop on DAQ error, weak/unstable output or excessive voltage drop.
- Saved NI-MAX task: `success_cue_test_Dev1`
  - Physical channel: `Dev1/port0/line1`
  - Digital line output, not inverted
  - Generation: 1 Sample (On Demand)
- Final task: `SuccessCue_Dev1` on the same line, one-sample/on-demand.
- Direct LOW→HIGH→LOW test passed on 06/08/26: HIGH produced a loud, clear high-pitched tone and
LOW silenced it; no NI-MAX error reported.
- Buzzer leads subsequently soldered and insulated, connected permanently to terminals 17/15, and
the LOW→HIGH→LOW NI-MAX test passed again.
- Working VI writes HIGH, waits a configurable 50 ms bench duration, then writes LOW immediately on
success. End-to-end runtime test passed.
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

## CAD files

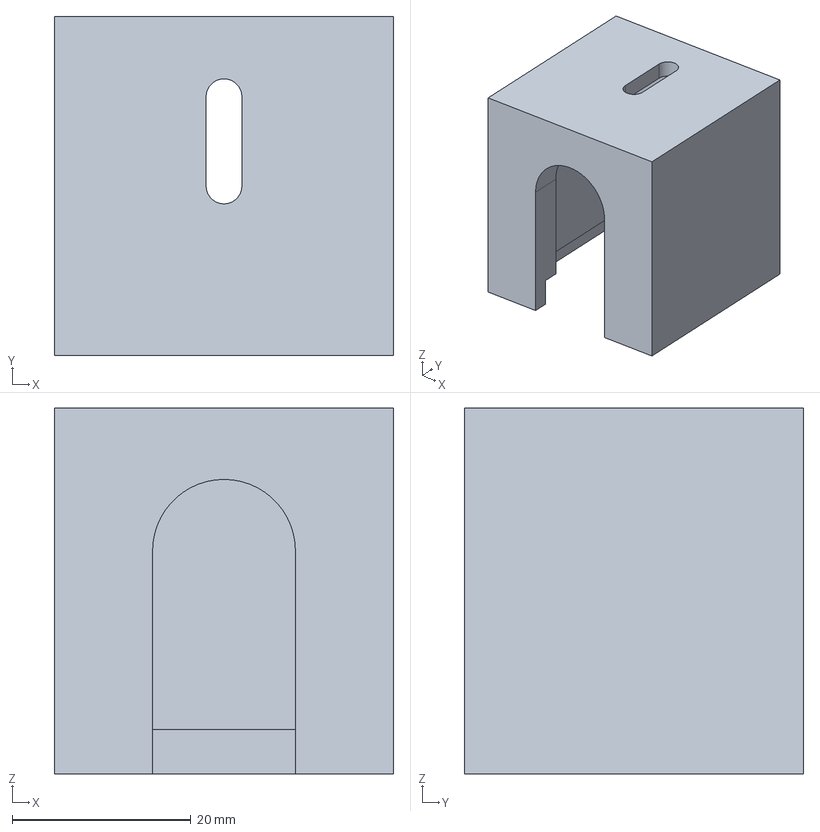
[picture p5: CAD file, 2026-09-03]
mechanical/3d-print/joystick-1d-axis-constrainer/joystick_1d_axis_constrainer_38x38x41.step
38.0 x 38.0 x 41.0 mm

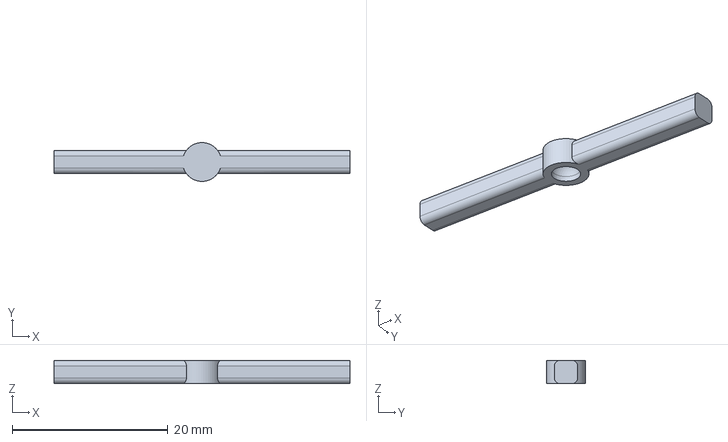
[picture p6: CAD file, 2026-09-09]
mechanical/3d-print/joystick-handle-bar/joystick_handle_bar_38mm.step
38.0 x 4.99 x 3.00 mm

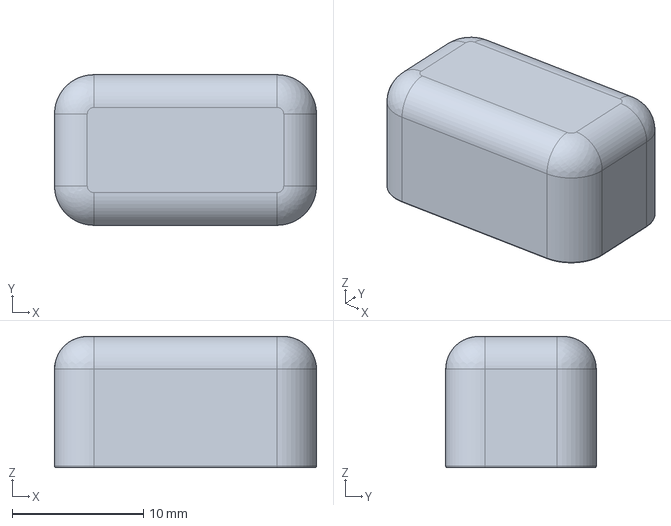
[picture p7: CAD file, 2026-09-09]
mechanical/3d-print/joystick-handle-cube/joystick_handle_cube.step
20.0 x 11.5 x 10.0 mm

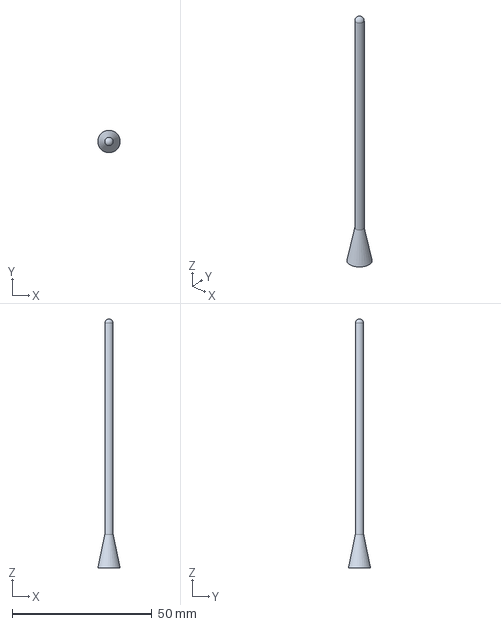
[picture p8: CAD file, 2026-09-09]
mechanical/3d-print/joystick/joystick_89mm.step
7.99 x 8.00 x 89.0 mm

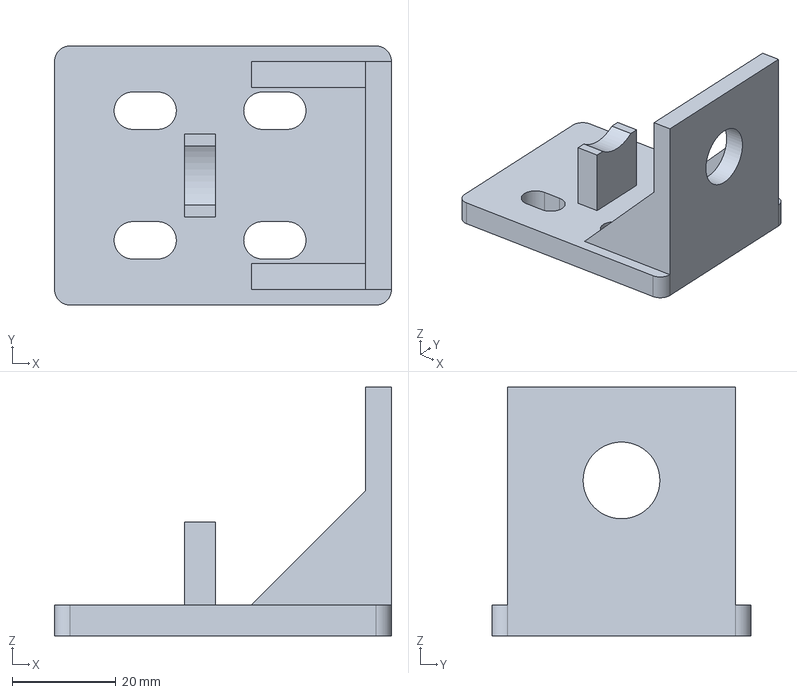
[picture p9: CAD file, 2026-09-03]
mechanical/3d-print/ledex-holder/ledex_195224-230_holder_30mm_axis.step
65.0 x 50.0 x 48.0 mm

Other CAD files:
mechanical/3d-print/joystick-1d-axis-constrainer/joystick_1d_axis_constrainer_38x38x41.stl
mechanical/3d-print/joystick-handle-bar/joystick_handle_bar_38mm.stl
mechanical/3d-print/joystick-handle-cube/joystick_handle_cube.stl
mechanical/3d-print/joystick/joystick_89mm.stl
mechanical/3d-print/ledex-holder/ledex_195224-230_holder_30mm_axis.stl

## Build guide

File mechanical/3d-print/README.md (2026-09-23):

# 3D-printed parts

Current models are provided as editable STEP sources and slicer-ready STL exports:

- [Joystick shaft](joystick/README.md) — 89 mm shaft that the interchangeable handles mount onto
- [Joystick bar handle](joystick-handle-bar/README.md) — 38 mm bar that attaches at the shaft tip
- [Joystick rounded-cube handle](joystick-handle-cube/README.md) — rounded box with three offset holes
- [Joystick 1D-axis constrainer](joystick-1d-axis-constrainer/README.md) — constrains the joystick to one movement axis
- [Ledex holder](ledex-holder/README.md) — holder for the Ledex `195224-230` axial-resistance solenoid

Keep one subfolder per part (or per design iteration), for example:

```
3d-print/
  lateral-delimiter/
  fsr-rest-pad-mount/
  lick-spout-carriage/
```

Supported formats: STL, 3MF, STEP, or native CAD project files. Include a one-line note in the
part README or filename if print orientation, infill, or material matters for the rig.

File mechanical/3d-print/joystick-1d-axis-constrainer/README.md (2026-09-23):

# Joystick 1D-axis constrainer

STEP model for the 38 × 38 × 41 mm stepped hollow box that mechanically constrains the joystick
to one movement axis.

- STEP source: [`joystick_1d_axis_constrainer_38x38x41.step`](joystick_1d_axis_constrainer_38x38x41.step)
- STL export: [`joystick_1d_axis_constrainer_38x38x41.stl`](joystick_1d_axis_constrainer_38x38x41.stl)
- Fabrication and fit on the current rig have not yet been documented here.

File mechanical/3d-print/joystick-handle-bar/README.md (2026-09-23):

# Joystick bar handle

Interchangeable bar handle that slides onto the tip of the
[89 mm joystick shaft](../joystick/README.md).

- STEP source: [`joystick_handle_bar_38mm.step`](joystick_handle_bar_38mm.step)
- STL export: [`joystick_handle_bar_38mm.stl`](joystick_handle_bar_38mm.stl)
- Approximate CAD extent: 38 × 3 × 3.1 mm bar
- Alternative to the [rounded-cube handle](../joystick-handle-cube/README.md)
- Not yet printed, fitted, or validated on the rig

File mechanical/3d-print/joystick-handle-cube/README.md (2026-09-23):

# Joystick rounded-cube handle

Interchangeable rounded-box / cube handle that slides onto the tip of the
[89 mm joystick shaft](../joystick/README.md). This is the current push-object
candidate: a compact contact surface meant to sit below the mouse and encourage
a forward push rather than a grasp.

- STEP source: [`joystick_handle_cube.step`](joystick_handle_cube.step)
- STL export: [`joystick_handle_cube.stl`](joystick_handle_cube.stl)
- Approximate CAD extent: 20 × 11.5 × 10.1 mm rounded box
- Three mounting holes let the cube sit at different offsets along the shaft.
  That changes how close the front face is to the mouse and rest pad, and it
  also shifts the object's weight relative to the joystick beneath it
- Alternative to the [bar handle](../joystick-handle-bar/README.md)
- Not yet printed, fitted, or validated on the rig. Spring return, steel washer
  target, and rest-pad-to-object geometry still need to be frozen after a
  physical fit check

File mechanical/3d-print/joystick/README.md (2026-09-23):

# Joystick shaft

STEP model of the 89 mm joystick shaft that both interchangeable handles mount onto.

- STEP source: [`joystick_89mm.step`](joystick_89mm.step)
- STL export: [`joystick_89mm.stl`](joystick_89mm.stl)
- Approximate CAD extent: 89 mm along the shaft axis; conical body from a 4 mm-radius base
  toward a 1.5 mm-radius tip
- Both the [bar handle](../joystick-handle-bar/README.md) and the
  [rounded-cube handle](../joystick-handle-cube/README.md) attach at the tip
- Not yet printed, fitted, or validated on the rig

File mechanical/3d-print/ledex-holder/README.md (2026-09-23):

# Ledex axial-solenoid holder

STEP model for a holder designed around the 30 mm axis of the Ledex `195224-230` tubular
solenoid used for axial push resistance.

- STEP source: [`ledex_195224-230_holder_30mm_axis.step`](ledex_195224-230_holder_30mm_axis.step)
- STL export: [`ledex_195224-230_holder_30mm_axis.stl`](ledex_195224-230_holder_30mm_axis.stl)
- The holder has not yet been documented as printed, fitted, or validated on the rig.

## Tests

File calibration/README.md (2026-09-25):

# Calibration

Hardware calibrations for the training-rig push task. Each page is one measurement,
dated, with the raw numbers and the value to use in LabVIEW.

| Calibration | Status | Date |
| --- | --- | --- |
| [Water volume vs valve pulse](water-volume.md) | Done — use 130 / 185 / 240 ms for 4 / 6 / 8 µl | 8 Sep 2026 |
| [Joystick home + volts → mm](joystick-volts-mm.md) | Push = Y / `ai1` / white; lateral = X / `ai0` / red. Rest 2.50 / 2.525 V; ~0.030 V/mm eyeball | 8 Sep 2026 |
| FSR threshold / hysteresis | Not yet (taped replacement working) | — |
| Spout extend voltage vs mouse | Not yet | — |
| Magnet force vs AO0 | Driver ordered 25 Sep 2026 (Hydraulik-Kompetenz PVA 1.6 0–10 V); not yet installed | — |

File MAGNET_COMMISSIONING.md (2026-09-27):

# Ledex / PVA 1.6 commissioning handoff

**Status 27/09/2026:** The Hydraulik-Kompetenz **PVA 1.6 0–10 V** driver is now physically
available at the training rig. The Ledex `195224-230`, reserved 12 V / 1 A Goobay supply,
`MagnetPush_Dev1` NI-MAX task and LabVIEW AO0 path already exist, but the driver and coil have
not yet been wired or powered together.

This page is the handoff for the rig-PC AI agent. Guide the user through one checkpoint at a
time, record actual measurements, and update `.cursorrules` after every completed step. Do not
skip ahead after a failed measurement.

## Safety and Sunday scope

- Keep the Class 3B laser keyed **off** throughout.
- No animal and no experimental parameter file during commissioning.
- Secure the driver and Ledex before power. Keep fingers, loose steel tools and the washer target
  away during first energisation.
- Never open or alter the mains side of the power adapter.
- The PVA can source up to 3 A even though the Ledex is nominally only about 0.58 A. Install a
  **1 A inline fuse** in the 12 V positive lead before powered testing. If no fuse is available,
  stop after unpowered inspection and wiring preparation.
- The printed Ledex holder is not proven to provide the heatsinking assumed by the continuous-duty
  coil rating. Use only short pulses with long cool-downs today.
- Stop for a blown fuse, unstable current, failure to release at 0 V, rapid heating, smoke/odour,
  unexpected LED state, binding or incorrect force direction.

Primary driver datasheet:
<https://www.hydraulikshop.ch/ftp/PVA_1.6_0919.pdf>

The shop description contains a `0–10 mA` typo. The ordered product and datasheet variant are
**0–10 V differential input**. Confirm the physical unit says 0–10 V; stop if it is the 4–20 mA
variant.

## Known hardware limits

- Ledex `195224-230`: 12 VDC, 7 W, approximately 20.7 ohm, nominal current approximately
  `12 / 20.7 = 0.58 A`.
- NI PCIe-6321 AO0: ±10 V range but only ±5 mA drive. Power-on/off can glitch as high as 2 V for
  500 ms, so keep the PVA Enable open until AO0 is initialised and measured at 0 V.
- AO0 command: `Dev1/ao0`, SCB-68A terminal **22**.
- AO0 reference: AO GND, SCB-68A terminal **55**.
- The coil must be powered by the reserved 12 V supply through the PVA, never by AO0.

## PVA terminal map

- `D`: +12–36 V supply (`+Ub`)
- `F`: power ground
- `E`: earth / chassis function
- `J`: Enable; below 1 V is disabled, above 4 V is enabled
- `K`: internal +10 V reference; unused here
- `M`: signal ground for the local-reference circuit; unused here
- `H`: positive 0–10 V command input
- `G`: negative command input
- `C`: positive coil output
- `A`: negative coil output

The LED should be red while disabled and green while enabled. Do not guess or jumper `F`, `G`
and `M` together. Do not improvise a mains-earth connection to `E`.

## Checkpoint 1 — unpowered preflight

With all power disconnected:

1. Confirm the driver is the 0–10 V model.
2. Measure and record the Ledex resistance. Expected cold value is approximately 20.7 ohm;
   roughly 18–22 ohm is a reasonable initial acceptance band.
3. Check that neither coil lead is shorted to the Ledex case.
4. Identify the adapter's positive and negative **low-voltage** conductors with the DMM.
5. Measure PVA `H–G` resistance as an initial AO-input screen. Stop if below 2 kohm, because
   10 V / 2 kohm already reaches the NI AO0 5 mA limit. A high or unstable semiconductor reading
   is only a preliminary screen.
6. Secure the PVA and Ledex mechanically.

Record the values before proceeding.

## Checkpoint 2 — wiring, still unpowered

Wire:

```text
12 V PSU +  ── 1 A inline fuse ──> PVA D
12 V PSU −                       ──> PVA F

SCB-68A terminal 22 / AO0        ──> PVA H
SCB-68A terminal 55 / AO GND     ──> PVA G

PVA C                            ──> Ledex lead 1
PVA A                            ──> Ledex lead 2

PVA D ── removable switch/jumper ──> PVA J Enable
                                      (leave open)
```

Leave `K` and `M` unused. Handle `E` only as part of an established lab chassis/functional-earth
scheme. Do not add a random external flyback diode across `C/A`: the PVA is itself a PWM
inductive-load driver, and an external diode may alter current regulation and release time.

## Checkpoint 3 — disabled power and AO command

1. Disconnect the coil for this checkpoint and leave Enable `J` open.
2. Set `Imin` and gain / `Imax` to their minimum positions without forcing the trimmer end stops.
   Leave dither at the factory position initially.
3. Power the 12 V supply. Measure about 12 V across `D–F`; the PVA LED should be red. Stop if it
   is green with `J` open, or if there is heating or smell.
4. In NI-MAX, initialise `MagnetPush_Dev1` to **0.0 V**. Before connecting `H`, measure terminal
   22 relative to 55 and confirm 0 V.
5. Connect `H/G`, then verify that commands of 0 V and small positive steps are reproduced across
   `H–G`. Never command a negative voltage.

If the DMM can safely measure the command-input current, measure it at 10 V while the output remains
disabled; it must be below 5 mA. Recheck the DMM lead sockets before returning to voltage mode.

## Checkpoint 4 — establish coil current with short pulses

1. Power off and insert the DMM in series with the coil on its suitable high-current range.
2. Keep the steel target away. Reconnect the coil, initialise AO0 to 0 V, power the PVA, then close
   the removable Enable jumper.
3. At a 0 V command, coil current must be effectively zero. Adjust `Imin` toward zero if needed.
   Stop if it energises strongly at 0 V.
4. Apply approximately 0.5-second pulses at `0.5, 1, 2, 3, 4, 5 V`, with at least 10 seconds off
   between pulses. Record command voltage, current, supply voltage, sound, release and temperature
   trend.
5. Continue toward 9–10 V only if current is stable, the coil remains cool and current stays below
   **0.58 A**. Measured current is authoritative. At the published minimum gain, rough expectations
   are 0.30 A at 5 V and 0.54 A at 9 V, but the 12 V supply leaves little driver headroom.
6. Establish and record the maximum allowed AO command that does not exceed 0.58 A cold.
7. Confirm that returning AO0 to 0 V removes current promptly. Open Enable before changing wiring.

## Checkpoint 5 — mechanical direction

Mount the Ledex on the **home side** of the object so attraction toward the steel washer opposes
the forward push. Start with a generous air gap and the lowest proven command. Verify:

- resistance is backward, not assistive;
- the object and target cannot collide with the Ledex;
- the spring returns the object;
- the 1D mechanism does not bind;
- current returns to zero and force releases at 0 V.

Sunday's successful endpoint is a repeatable, low-duty pull at known current with clean release.
Do not claim force calibration without a force gauge or load cell. A later calibration must map
AO command to force at the actual operating gap and characterize heating across repeated trials.

## Existing LabVIEW behavior and later code work

No LabVIEW edit is required for initial electrical commissioning:

- NI-MAX task `MagnetPush_Dev1` owns only `Dev1/ao0`.
- The main VI currently wakes the magnet loop at trial Case 2, writes scalar parameter `mag`,
  waits `magtime`, then writes 0 V.
- Safe startup already writes `MagnetPush_Dev1 = 0 V`.
- Normal Stop has been validated to end all loops without DAQ errors.
- Every current training/bench parameter file keeps `mag = 0`; leave them that way.

Before animal use or any nonzero experiment file, the canonical VI still needs:

1. a clamp from 0 V to the measured safe maximum;
2. guaranteed 0 V on success, timeout, Stop and DAQ/error paths;
3. logged command, calibration version, onset and offset;
4. verification of magnet-loop trial indexing;
5. later replacement of the Case-2 timed pulse with movement-onset activation held until trial
   end, matching the axial-resistance design.

Record actual wiring, measurements and outcomes in `RIG_INVENTORY.md` and
`calibration/README.md`, and update `.cursorrules` after each completed checkpoint.

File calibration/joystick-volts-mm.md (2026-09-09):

# Joystick home voltage and volts → mm

Training rig · 8 September 2026 · eyeball 10 mm on the fitted printed handle.
Do not trim the red joystick regulator.

## Axis map (confirmed 8 Sep 2026)

NI-MAX: **Voltage_1 / `Dev1/ai1` = push**. **Voltage_0 / `Dev1/ai0` = lateral**.

| Physical | Graph | DAQ | LabVIEW name | Queue index | Param-file box |
| --- | --- | --- | --- | --- | --- |
| **Push** | white | `ai1` | **Y** (`Y_POS`) | **0** | 2nd and 4th numbers |
| **Lateral** | red | `ai0` | **X** (`X_POS`) | **1** | 1st and 3rd numbers |

`joysticklickframe_push` order is `[ai1, ai0, ai2]` = Y, X, FSR. Matches this.

## Rest (home)

| Axis | LabVIEW live graph | Rest | Noise |
| --- | --- | --- | --- |
| Push (Y, `ai1`) | white | **2.50 V** | ±0.035 V |
| Lateral (X, `ai0`) | red | **2.525 V** | ±0.035 V |

Mathis demo rest was **2.55 V**. 2.50 V is close enough; leave the regulator alone.

## Push-axis scale (provisional)

Pushing ~10 mm dropped the white trace from **2.50 V → 2.20 V** (Δ = 0.30 V).

| | V / mm | 10 mm |
| --- | --- | --- |
| This measurement (eyeball 10 mm) | **0.030** | 0.30 V |
| Mathis pull-task docs | 0.050 | 0.50 V |

Direction: forward push **lowers** voltage. That is the sign to use in the `end` box.

0.03 V/mm is **not** a contradiction of 0.05 V/mm. The pot reports angle; millimetres are at the contact point. A longer shaft/handle gives **fewer volts per mm**. The 10 mm mark was also by eye (at 0.05 V/mm, 0.30 V would be 6 mm). Remeasure with a ruler before writing training files.

Noise ±0.035 V is ~1 mm on this provisional scale (~0.7 mm on the old 0.05 scale). Micro-push (~0.5–1 mm) will sit near the noise floor until the scale is cleaner.

## File used on 8 Sep 2026 bench

`Full_shoterPull_Training_Task_RIG1.txt` — identical-row shorter-**pull** training file
(~1000 lines). Not a push file. One row:

```text
2.39  2  2.8  3  500  2  2  2.35  2.7  0  1.8  2.45  2.34  2.55  50  0  25  200  1000  400  0
```

| Cols | Field | This file |
| --- | --- | --- |
| 1–4 | `home` box | (2.39, 2) to (2.8, 3) — rest 2.50 / 2.525 sits inside |
| 5 | `home TO` | 500 ms (plus FSR gate) |
| 6–9 | `start` box | (2, 2) to (2.35, 2.7) |
| 10 | `start TO` | **0** (start wait off) |
| 11–14 | `end` box | (1.8, 2.45) to (2.34, 2.55) |
| 15 | `end TO` | 50 ms |
| 16–17 | `mag` / `magtime` | 0 / 25 |
| 18 | `watertime` | 200 ms (= 6.6 µl on this rig) |
| 19 | `timeout` (Case 0 ITI) | **1000** |
| 20 | `move time` (Case 3) | **400** |
| 21 | `light` | 0 |

End rectangle as two corners `(x1,y1)–(x2,y2)` (X = lateral, Y = push):

- **X / lateral: 1.80–2.34 V.** Rest 2.525 V is **outside** this band. The old pull target was a sideways move on `ai0`.
- **Y / push: 2.45–2.55 V.** Rest 2.50 V is **inside**. A forward push to **2.20 V** is **outside**.

This file rewards: move **X** down toward ~2.0 V and keep **Y** near 2.50 V. A straight push (white 2.50→2.20, red stuck at 2.525) should **not** hit the end box. If a push still paid out, the live unbundle may not match this column map — re-check before writing push files.

A real push `end` box should put the **Y** pair (2nd and 4th numbers) a few mm below 2.50 V, and make the **X** pair (1st and 3rd) wide around 2.525 V.

Unbundle confirmed 08/09/26: column 19 = `timeout` (1000 ms ITI), column 20 =
`move time` (**400 ms** movement window). That is why misses flipped back to
the rest pad so fast and why there was no time to overshoot-and-correct.

First push bench file: [`parameters/push_bench_wide-zone.txt`](../parameters/push_bench_wide-zone.txt)
(`move time` 3000 ms, Y end 2.20–2.35, wide X).

## Still to confirm on the VI

- Loader Case 2 has no ×2 (09/09/26).
- If a pure forward push (Y to 2.20, X at 2.525) still got reward on the shorter-pull file, something else is off — that file’s Y end is 2.45–2.55.

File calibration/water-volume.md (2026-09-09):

# Water volume vs valve pulse

Training rig · 8 September 2026 · `Water_Dev1` · `watertime` in the working VI.

After the line is primed and bubble-free, delivered volume is linear with pulse
length above ~100 ms:

```text
µl / pulse  =  0.0350 × t(ms)  −  0.48
```

R² = 0.998. About 14 ms of valve opening delay, then **0.035 µl per ms**
(~**30 ms per extra µl**). Do not use a single ratio through the origin; 50 ms
is less efficient.

## Use these pulse lengths

| Target drop | From the fit | Set in LabVIEW |
| --- | --- | --- |
| 4 µl | 128 ms | **130 ms** |
| 6 µl | 185 ms | **185 ms** |
| 8 µl | 242 ms | **240 ms** |

The old bench default of **200 ms was 6.6 µl**, not 4–6 µl.

## Curve

Cup weight after 50 pulses (empty cup 2.94 g):

Cup weight versus pulse duration

Same data as microlitres per pulse, with the linear fit and the 4 / 6 / 8 µl targets:

Delivered microlitres per pulse versus pulse duration

## Raw measurements

Empty cup: **2.94 ± 0.02 g**. Fifty pulses per condition, caught in the cup under
the spout (tip not scraped). 1 g = 1000 µl.

| Pulse (ms) | Cup (g) | Water (g) | Total (µl) | µl / pulse | ms / µl |
| ---: | ---: | ---: | ---: | ---: | ---: |
| 50 | 3.00 | 0.06 | 60 | 1.2 | 41.7 |
| 100 | 3.10 | 0.16 | 160 | 3.2 | 31.3 |
| 150 | 3.17 | 0.23 | 230 | 4.6 | 32.6 |
| 200 | 3.27 | 0.33 | 330 | 6.6 | 30.3 |
| 300 | 3.44 | 0.50 | 500 | 10.0 | 30.0 |

Tare uncertainty ±0.02 g is about **±0.4 µl / pulse**. Fine for choosing 130 / 185 / 240 ms.

## Method notes

- Measure mass in a cup under the spout. Do not try to wick the lick tube with a
  capillary; the tip is meant to hold a film.
- Prime until bubble-free before a run. Short pulses fail if there is air in the
  line (seen 18/08/26).
- Recalibrate if the valve, tubing, height of the reservoir, or needle/spout tip
  changes.

## LabVIEW

`watertime` is still a per-trial parameter-file field (column in the 21-wide
file), not a new front-panel control. Session-constant cue / delay / spout
voltages stay on the front panel until that map is confirmed.

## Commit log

2026-08-20 Refresh README after LabVIEW integration.
    Distinguish bench-validated functionality from remaining mechanical, calibration, parameter, and safety work.
2026-08-20 Fix rig dependency and preserve NI-MAX configuration.
    Use the LabVIEW-compatible frame counter so fresh clones run on the behavioural rig, and archive the validated DAQ task configuration after correcting X/Y order.
2026-09-03 Document mechanical prototypes and current rig status.
    Add fabrication sources and align project documentation and build metadata with received hardware and outstanding validation.
    [joystick_1d_axis_constrainer_38x38x41.step, ledex_195224-230_holder_30mm_axis.step]
2026-09-09 Document calibrated push-task setup and training presets.
    Record the current rig mechanics and calibrations, and add 27-column stage files so push training and reward timing are reproducible.
    [joystick_89mm.step, joystick_handle_bar_38mm.step, joystick_handle_cube.step]
2026-09-23 Add STL exports and remove obsolete laser-cut design.
    [joystick_1d_axis_constrainer_38x38x41.stl, joystick_89mm.stl, joystick_handle_bar_38mm.stl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]
2026-09-25 Record the ordered Hydraulik PVA driver for the Ledex.
    The 0–10 V PVA 1.6 is the selected coil driver, so rig notes no longer treat the magnet install as blocked on procurement.
2026-09-27 Add safe commissioning handoff for the Ledex driver.
    Give the rig-side operator and agent a measured, checkpointed setup path before any nonzero magnet trials.
2026-09-29 Record non-capacitive alternatives to the SingleTact paw sensor.
    Keeps SingleTact as the preferred sensor and documents the strain-gauge
    load cell plus amplifier route and rejected options as fallback context.
2026-09-29 Record the user-confirmed live rig status in the shared plan.
    The merged notes still disagreed about the acquisition read, rest-pad hardware, home voltage, spout startup, and the Ledex fuse. Both machines should follow the 29 Sep confirmation.
2026-09-29 Record the SingleTact sensor plan and confirm the 27-column parameter order.
    Document request 1 for RobotShop CS8-1N (no tail extender) and align parameters/README.md with the live loader and cluster-order fix already on master.
2026-10-01 Update the project plan with PPS UK SingleTact sourcing, fuse procurement, and interim mouse habituation.
2026-10-01 Add the EVENTS logger foundation for the push task.
    Introduce Log Event.vi, a sample count global, and the main VI writer loop so trial events can be recorded for the DataJoint pipeline. State-machine and reward-loop logging calls are still to come.
2026-10-02 Log trial, reward, magnet and heartbeat events to the EVENTS file and fix the stale session-start sample.
2026-10-05 Update the 1D-axis constrainer CAD to the 38×38×56 mm revision.
    Replace the previous 38×38×41 mm STEP/STL with the user-edited taller model and refresh the mechanical READMEs.
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2026-10-11 Add the Ledex commissioning details and the re-clone note to the plan.
2026-10-11 Record the Ledex current curve, the plunger findings and the deferred force test.
2026-10-11 Add the FEMM Ledex field and target-force model with sweep results and plots, and record the completed current commissioning.
2026-10-11 Fix the Ledex model geometry from the datasheet drawing, make every parameter overridable and replace the PowerShell runners with femm_run.py.
2026-10-11 Add the Ledex STA 20x40 datasheet and the digitized 60-degree force-stroke curves.
2026-10-11 Calibrate the FEMM model against the datasheet curves with a held-out check and an accepted-fit band.
2026-10-11 Rerun all Ledex sweeps and figures with the calibrated model and document the calibration.
2026-10-12 Take the field profile along the plunger outer edge instead of the slotted axis.
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2026-10-12 Tighten the calibration fit figure layout.
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2026-10-12 Redraw the 3D field figure with the solenoid horizontal and the washer tower vertical.
2026-10-12 Add 1 mm and 3 mm gap field figures and put all four target rows in the overview.
2026-10-12 Tighten the row spacing in the overview figure.
2026-10-12 Rename figures/readable to figures/magnetic_fields, drop FEMM-based field code and refresh the README and plan for the 3D results.
2026-10-12 Rename the result files into femm/ and fea3d/ folders, add the 3D calibration band and finish the sweep.
2026-10-12 Model the plunger linked to the joystick with spring sizing and 2D/3D views.
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2026-10-15 Add measured rig geometry, washer-versus-link force comparison, adjustable Ledex holder and rig explorer.
2026-10-15 Model the Ledex plunger from the datasheet drawing and open the constrainer window for the link.
2026-10-15 Seat the shaft on the component stub, lengthen the link and make the Ledex holder adjustable with the solenoid fitted.
2026-10-16 Share one Ledex geometry across the CAD, FEMM and 3D models, use the real slotted tip in 3D and fix the holder height range.
2026-10-16 Describe the capacitive rest pad in the docs, archive the FSR bench logs and rename the pad-contact shaping presets.
2026-10-16 Archive the old Ledex holder, remove the 2016 screenshots and update the docs table of contents.
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2026-10-16 Filter 50 Hz mains hum in the rest-pad sketch and add a chatter report script.
2026-10-16 Place the shaft in the front hole of the cube and recompute forces.
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2026-10-18 Keep the magnet fixed when the pivot depth changes in the rig explorer.
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2026-10-18 Add a set-default button resetting all rig explorer sliders.
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2026-10-22 Add optional velocity reward mode with a 28th parameter column and parameter files.
2026-10-24 Add smoothed 200 ms velocity look-back to the push VI and the 0.006 velocity parameter files.
2026-10-24 Restore historical day-one parameter files, add the session-to-file map and make the timing clock fit robust to stalls.
2026-10-27 Update push VI and add smoothed 200 ms velocity training parameter files.
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2026-10-30 Fix anaconda distance file home band and add zuchon pad plus velocity file.
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2026-10-30 Add 200 ms hold, 1.5 ul, 3 s move-time velocity file for blackmamba.
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2026-11-02 Add zuchon mixed 10 s file and 2.46-2.51 V distance file, remove unused 04 file.
2026-11-02 Update push behaviour VI, parameters README and add velocity training parameter file.
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2026-11-04 Record measured push-axis calibration and add 2 ul pad-touch and end2p40 distance files.
2026-11-05 Add handle-cube CadQuery script and 15.1 mm revision with deeper shaft holes.
2026-11-05 Add pad-touch and micro-touch velocity training parameter files and update the parameters README.
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
